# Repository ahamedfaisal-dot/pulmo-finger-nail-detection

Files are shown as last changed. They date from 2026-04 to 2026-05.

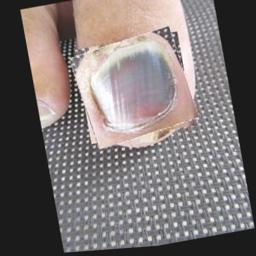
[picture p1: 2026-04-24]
rpi_input1/bf.jpg

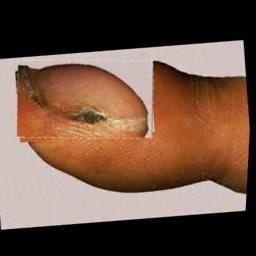
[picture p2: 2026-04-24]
rpi_input1/cl.jpg

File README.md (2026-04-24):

# Finger-Based Lung Health Classification System

> **Edge AI · Raspberry Pi · MobileNetV2 · CAM Explainability · Multi-Sensor Fusion**

A non-invasive, real-time lung health screening system that classifies three clinical conditions directly from a fingertip photograph, fused with live biometric readings (temperature, heart rate, SpO₂) — all running on a Raspberry Pi 4 as a self-contained medical edge device.

---

## Table of Contents

1. [Clinical Background](#-clinical-background)
2. [System Architecture](#-system-architecture)
3. [Project Structure](#-project-structure)
4. [Machine Learning Pipeline (PC / Training Side)](#-machine-learning-pipeline-pc--training-side)
5. [Raspberry Pi Deployment (rpi\_input/)](#-raspberry-pi-deployment-rpi_input)
   - [Hardware Requirements](#hardware-requirements)
   - [Wiring Diagram](#wiring-diagram)
   - [Software Setup on RPi](#software-setup-on-rpi)
   - [Running the System](#running-the-system)
   - [Web Interface &amp; Endpoints](#web-interface--endpoints)
   - [LED Feedback System](#led-feedback-system)
   - [Database &amp; Reports](#database--reports)
6. [Grad-CAM Explainability](#-grad-cam-explainability)
7. [3D Printed Enclosure](#-3d-printed-enclosure)
8. [Troubleshooting](#-troubleshooting)
9. [Class Definitions](#-class-definitions)

---

## Clinical Background

Certain lung and oxygenation disorders manifest visually in the fingertips:

| Condition | Visual Indicator | Root Cause |
| --- | --- | --- |
| **Bluefinger (Cyanosis)** | Bluish/purple discoloration | Severe oxygen deficiency (SpO₂ < 85%) |
| **Clubbing** | Rounded, bulging fingertips | Chronic lung disease (COPD, fibrosis, cancer) |
| **Healthy** | Normal pink coloration | Normal lung function |

This system automates the visual assessment by training a deep CNN on finger images and fusing the result with real-time SpO₂ and temperature data from hardware sensors.

---

## System Architecture

```
┌─────────────────────────────────────────────────────────┐
│                   TRAINING SIDE (PC/GPU)                 │
│                                                          │
│   train/ dataset  ──►  train_export.py                  │
│   (3 classes,         MobileNetV2 fine-tune             │
│    256×256 images)    15 epochs, best_model.pt          │
│                        │                                │
│                        ▼                                │
│                   export_cam.py                         │
│                   (hook last conv layer)                │
│                   Finger19_lung_cam.onnx +              │
│                   cam_weights.npy                       │
└──────────────┬──────────────────────────────────────────┘
               │   Copy .onnx + .npy  via SCP/USB
               ▼
┌─────────────────────────────────────────────────────────┐
│               RASPBERRY PI 4 (Edge Device)               │
│                                                          │
│  ┌─────────────┐   ┌───────────────┐  ┌──────────────┐ │
│  │  RPi Camera │   │  MLX90614     │  │  MAX30102    │ │
│  │  (rpicam)   │   │  IR Temp      │  │  HR + SpO₂  │ │
│  └──────┬──────┘   └───────┬───────┘  └──────┬───────┘ │
│         │                  │  I²C Bus         │         │
│         ▼                  └─────────┬────────┘         │
│    image_bytes              sensor_utils.py             │
│         │                            │                  │
│         └────────────┬───────────────┘                  │
│                      ▼                                   │
│               rpi_input/app.py                          │
│               Flask Web Server (:5000)                  │
│                      │                                   │
│          ┌───────────┼───────────────┐                  │
│          ▼           ▼               ▼                  │
│     ONNX Inference  CAM         SQLite DB               │
│     (3-class pred)  Overlay     diagnostics.db          │
│          │                           │                  │
│          ▼                           ▼                  │
│     LED GPIO Pins               PDF Reports             │
│     (17 / 27 / 22)              via /report/<id>        │
└─────────────────────────────────────────────────────────┘
```

---

## Project Structure

```
Finger_256_lung/
│
├── train/                        # Training dataset (not committed – see .gitignore)
│   ├── Bluefinger/               # Class 0: Oxygen deficiency
│   ├── Clubbing/                 # Class 1: Chronic lung disease
│   └── Healthy/                  # Class 2: Normal
│
├── test/                         # Held-out test images
│
├── train_export.py               # Main training script (MobileNetV2 → ONNX)
├── export_cam.py                 # Exports CAM-capable ONNX + cam_weights.npy
├── inspect_mat.py                # Utility to inspect .mat dataset files
│
├── Finger19_lung.onnx            # Standard ONNX model (no CAM outputs)
├── best_model.pt                 # PyTorch checkpoint (best validation accuracy)
│
├── app.py                        # Standalone Flask demo (PC use, no sensors)
├── requirements.txt              # PC/dev dependencies
│
├── rpi_input/                    # ← DEPLOY THIS FOLDER TO THE RASPBERRY PI
│   ├── app.py                    # Main RPi Flask application
│   ├── sensor_utils.py           # MLX90614 + MAX30102 driver & signal processing
│   ├── Finger19_lung_cam.onnx    # CAM-enabled ONNX model (2 outputs)
│   ├── cam_weights.npy           # Pre-extracted CAM classifier weights
│   ├── requirements_rpi.txt      # RPi Python dependencies
│   │
│   ├── templates/
│   │   ├── index.html            # Home page (live camera feed + upload)
│   │   ├── result.html           # Diagnosis result with CAM overlay
│   │   └── report.html           # Printable/shareable report page
│   │
│   └── hardware_3d_model/
│       └── enclosure.scad        # OpenSCAD enclosure design for the device
│
└── .gitignore
```

---

## Machine Learning Pipeline (PC / Training Side)

### Step 1 — Prepare the Dataset

Organize training images into sub-folders by class:

```
train/
  Bluefinger/   ← finger images showing cyanosis
  Clubbing/     ← finger images showing clubbing
  Healthy/      ← normal healthy finger images
```

Each image should be a clear, well-lit photograph of a fingertip (minimum 100 images per class recommended for good generalization).

### Step 2 — Install PC Dependencies

```bash
pip install torch torchvision onnx onnxruntime flask numpy Pillow opencv-python
```

Or use GPU-accelerated training (requires CUDA):

```bash
pip install torch torchvision --index-url https://download.pytorch.org/whl/cu118
```

### Step 3 — Train the Model

```bash
python train_export.py
```

**What this does:**

- Loads the dataset from `train/` using `ImageFolder`
- Applies data augmentation: random flip, rotation ±15°, color jitter
- Fine-tunes **MobileNetV2** (pretrained on ImageNet) with a 3-class head
- Trains for **15 epochs** with Adam optimizer (lr=1e-3, StepLR scheduler)
- Saves the best checkpoint as `best_model.pt`
- Exports a standard ONNX model: `Finger19_lung.onnx`

**Expected output:**

```
Using device: cuda
Classes: ['Bluefinger', 'Clubbing', 'Healthy']
Epoch 01/15 | Loss=0.9123 | Train=68.3% | Val=71.2%
...
Epoch 15/15 | Loss=0.1204 | Train=97.1% | Val=94.8%
Best val acc: 94.8%
Exported ONNX → Finger19_lung.onnx
```

### Step 4 — Export CAM-Capable Model

```bash
python export_cam.py
```

**What this does:**

- Hooks into MobileNetV2's final convolutional layer to extract feature maps
- Exports a dual-output ONNX: `Finger19_lung_cam.onnx`
  - **Output 0**: class logits `[1, 3]`
  - **Output 1**: feature maps from last conv layer `[1, C, H, W]`
- Saves the classifier weights as `cam_weights.npy` for fast CAM computation at inference

---

## Raspberry Pi Deployment (`rpi_input/`)

### Hardware Requirements

| Component | Model | Interface |
| --- | --- | --- |
| Microcontroller | Raspberry Pi 4 (2 GB+ RAM) | — |
| Camera | Official RPi Camera Module v2 or v3 | CSI ribbon cable |
| IR Temperature Sensor | MLX90614 | I²C (SDA/SCL) |
| Heart Rate + SpO₂ | MAX30102 | I²C (SDA/SCL) |
| Status LEDs | Standard 5 mm LEDs × 3 (Red, Yellow, Green) | GPIO (BCM) |
| Resistors | 220 Ω × 3 | In series with each LED |
| Enclosure | 3D printed (see `hardware_3d_model/enclosure.scad`) | — |

---

### Wiring Diagram

#### I²C Sensors (Both share the same I²C bus)

```
Raspberry Pi 4 GPIO Header
─────────────────────────────────────────────────────
Pin 1  (3.3 V)  ──────────────┬─── MLX90614 VIN
                              └─── MAX30102 VIN

Pin 6  (GND)    ──────────────┬─── MLX90614 GND
                              └─── MAX30102 GND

Pin 3  (SDA1)   ──────────────┬─── MLX90614 SDA
                              └─── MAX30102 SDA

Pin 5  (SCL1)   ──────────────┬─── MLX90614 SCL
                              └─── MAX30102 SCL
─────────────────────────────────────────────────────
```

> **Note:** Add 4.7 kΩ pull-up resistors from SDA and SCL to 3.3 V if your breakout boards don't already include them.

#### LED Indicators (GPIO BCM Numbering)

```
Raspberry Pi GPIO                LED
──────────────────────────────────────────────
GPIO 17 (Pin 11) ── 220 Ω ── [Blue/Red LED]   Bluefinger (Oxygen deficiency)
GPIO 27 (Pin 13) ── 220 Ω ── [Yellow LED]     Clubbing (Chronic lung disease)
GPIO 22 (Pin 15) ── 220 Ω ── [Green LED]      Healthy (Normal)
GND      (Pin 9) ──────────── All LED cathodes
──────────────────────────────────────────────
```

Only the LED corresponding to the predicted class illuminates after each scan. All others go LOW.

---

### Software Setup on RPi

#### 1. Flash OS & Enable Interfaces

Flash **Raspberry Pi OS (64-bit, Bookworm)** and enable required interfaces:

```bash
sudo raspi-config
```

- **Interface Options → Camera** → Enable
- **Interface Options → I2C** → Enable
- Reboot

#### 2. Verify Camera

```bash
rpicam-hello --timeout 3000
```

You should see a brief camera preview. If using a legacy camera with an older OS, ensure `dtoverlay=imx219` is in `/boot/config.txt`.

#### 3. Verify I²C Sensors

```bash
sudo apt install -y i2c-tools
i2cdetect -y 1
```

Expected output (addresses may differ slightly):

```
     0  1  2  3  4  5  6  7  8  9  a  b  c  d  e  f
50: -- -- -- -- -- -- -- 57                          ← MAX30102
5a: 5a -- -- -- -- -- -- --                          ← MLX90614
```

#### 4. Transfer Project Files

Copy the `rpi_input/` folder to the Pi (replace `<PI_IP>` with your Pi's IP address):

```bash
scp -r rpi_input/ pi@<PI_IP>:/home/pi/lung_system/
```

Or use a USB drive and copy manually.

**The critical files that must be present on the RPi:**

```
lung_system/
├── app.py
├── sensor_utils.py
├── Finger19_lung_cam.onnx      ← generated by export_cam.py on PC
├── cam_weights.npy             ← generated by export_cam.py on PC
├── requirements_rpi.txt
└── templates/
    ├── index.html
    ├── result.html
    └── report.html
```

#### 5. Install Python Dependencies

```bash
cd /home/pi/lung_system/
python3 -m venv venv
source venv/bin/activate
pip install --upgrade pip
pip install -r requirements_rpi.txt
```

> **Note on `onnxruntime`:** On Raspberry Pi (ARM64), install the ARM-optimized wheel if the standard pip install fails:
>
> ```bash
> pip install onnxruntime   # Try standard first
> # If it fails, use:
> pip install onnxruntime-aarch64
> ```

---

### Running the System

#### Manual Start

```bash
cd /home/pi/lung_system/
source venv/bin/activate
python app.py
```

The Flask server starts on **`http://0.0.0.0:5000`**. Access it from any device on the same network:

```
http://<PI_IP>:5000
```

#### Auto-Start on Boot (systemd Service)

Create a service file to start automatically:

```bash
sudo nano /etc/systemd/system/lunghealth.service
```

Paste the following (adjust paths as needed):

```ini
[Unit]
Description=Lung Health Classification System
After=network.target

[Service]
User=pi
WorkingDirectory=/home/pi/lung_system
ExecStart=/home/pi/lung_system/venv/bin/python /home/pi/lung_system/app.py
Restart=always
RestartSec=5

[Install]
WantedBy=multi-user.target
```

Enable and start:

```bash
sudo systemctl daemon-reload
sudo systemctl enable lunghealth.service
sudo systemctl start lunghealth.service
sudo systemctl status lunghealth.service
```

---

### Web Interface & Endpoints

| Route | Method | Description |
| --- | --- | --- |
| `/` | GET | Home page — shows live sensor readings, camera feed, and upload form |
| `/video_feed` | GET | MJPEG live camera stream (embedded in the home page) |
| `/get_sensors` | GET | JSON endpoint for live sensor polling (called via AJAX every 2 s) |
| `/capture_predict` | POST | Triggers `rpicam-jpeg` to capture a frame and run inference |
| `/predict` | POST | Accepts an uploaded image file and runs inference |
| `/report/<report_id>` | GET | Shows the full historical diagnostic report by UUID |

#### Example Sensor JSON Response (`/get_sensors`)

```json
{
  "temperature": 36.8,
  "heart_rate": 74,
  "spo2": 98
}
```

#### Example Prediction Flow

1. User places finger on MAX30102 sensor pad
2. Taps **"Capture & Analyse"** on the web UI
3. `rpicam-jpeg` captures a 640×480 JPEG in ~1 s
4. Image is preprocessed (resize → 256×256, ImageNet normalization)
5. ONNX inference runs → logits + feature maps
6. Softmax gives class probabilities
7. CAM overlay is generated from `cam_weights.npy` × feature maps
8. LED on predicted class GPIO pin goes HIGH
9. Result page shows:
   - Predicted class + confidence
   - All class probabilities
   - Original image + CAM heatmap overlay
   - Live sensor readings at time of capture
10. Result is saved to `diagnostics.db` with a unique report UUID

---

### LED Feedback System

The Raspberry Pi uses three GPIO-connected LEDs to provide instant physical feedback without needing to look at the screen:

```python
LED_PINS = [17, 27, 22]  # Index 0 = Bluefinger, 1 = Clubbing, 2 = Healthy
```

After each inference, only the LED at `LED_PINS[pred_idx]` is set HIGH; the rest are set LOW. This makes the result immediately visible even from a distance.

---

### Database & Reports

All diagnostic results are stored in **SQLite** at `diagnostics.db`:

```sql
CREATE TABLE diagnostics (
    id         TEXT PRIMARY KEY,     -- UUID
    timestamp  DATETIME,             -- Auto-set to current time
    temp       REAL,                 -- Body temperature (°C)
    hr         INTEGER,              -- Heart rate (BPM)
    spo2       INTEGER,              -- Blood oxygen (%)
    class_name TEXT,                 -- Predicted class label
    confidence REAL,                 -- Model confidence (%)
    img_b64    TEXT,                 -- Base64 original image
    cam_b64    TEXT                  -- Base64 CAM overlay image
);
```

Each report is accessible at:

```
http://<PI_IP>:5000/report/<uuid>
```

This URL can be shared, bookmarked, or opened via a QR code for printable clinic-style reports.

---

## 🔥 Grad-CAM Explainability

Class Activation Mapping (CAM) highlights **which pixels the model focused on** when making its decision. This is critical for clinical trust — it shows doctors whether the model is looking at the fingertip (correct) or the background (incorrect).

**How it works in this system:**

1. `export_cam.py` hooks into MobileNetV2's last convolutional layer during export
2. The ONNX model now outputs **two tensors**: logits and the feature map
3. `cam_weights.npy` stores the classifier's weight matrix `[3 classes × C channels]`
4. At inference: `CAM = ReLU( Σ w_c · feature_map_c )` for the predicted class
5. The resulting activation map is:
   - Upsampled to 256×256 with bicubic interpolation
   - Gaussian-blurred for smoothness
   - Converted to a JET colormap heatmap
   - Alpha-blended (70% weight) over the original image

The result reveals exactly which part of the finger — tip, nail, or skin — drove the classification decision.

---

## Troubleshooting

| Problem | Cause | Fix |
| --- | --- | --- |
| `rpicam-jpeg: command not found` | Camera tools not installed | `sudo apt install -y rpicam-apps` |
| Camera black screen / no output | Camera not enabled in raspi-config  | Run `sudo raspi-config` → Interface Options → Camera |
| `No module named 'smbus2'` | smbus2 not installed | `pip install smbus2` |
| `No module named 'RPi'` | RPi.GPIO not installed | `pip install RPi.GPIO` |
| I²C sensors not detected at `i2cdetect` | Wrong wiring or I²C not enabled | Check SDA/SCL connections; enable via raspi-config |
| ONNX model fails to load | Wrong path or missing file | Confirm `Finger19_lung_cam.onnx` is in the same folder as `app.py` |
| `onnxruntime` install fails on ARM | Incompatible wheel | Try `pip install onnxruntime-aarch64` or install from source |
| SpO₂ reads "Finger?" | Finger not placed on MAX30102 | Press fingertip firmly on sensor; signal threshold is `red > 5000` |
| SpO₂ reads "Calib..." | Buffer not full yet (< 150 samples) | Wait ~3 seconds after placing finger |
| LED not lighting | GPIO wiring issue | Verify LED polarity (long leg → GPIO, short leg → GND via 220 Ω) |
| Flask not accessible from phone | Wrong host binding | Ensure `app.run(host="0.0.0.0", port=5000)` — do NOT use `127.0.0.1` |

---

## Class Definitions

| Index | Class Name | Display Label | Clinical Meaning |
| ----- | --- | --- | --- |
| 0 | `Bluefinger` | Bluefinger – Oxygen Deficiency  | Peripheral cyanosis caused by low arterial O₂ saturation |
| 1 | `Clubbing` | Clubbing – Chronic Lung Disease | Nail clubbing associated with COPD, pulmonary fibrosis, lung cancer |
| 2 | `Healthy` | Healthy – Normal Lung Function  | Normal fingertip coloration, no clinical indicators |

---

> **⚠️ Disclaimer:** This system is an educational and research prototype. It is **not a certified medical device** and should not be used as the sole basis for any clinical diagnosis. Always consult a qualified healthcare professional.

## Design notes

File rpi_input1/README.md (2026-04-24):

# Raspberry Pi 4 - Finger Lung Health System

This sub-folder contains the code and configuration for running the system on a Raspberry Pi 4 Model B (4GB) with I2C health sensors.

## 1. Hardware Connections (I2C)

Both sensors are connected to the Raspberry Pi's I2C pins:
- **SDA**: Pin 3 (GPIO 2)
- **SCL**: Pin 5 (GPIO 3)
- **VCC**: 3.3V (Pin 1 or 17)
- **GND**: Ground (Pin 6, 9, etc.)

| Sensor | SDA | SCL | VCC | GND |
| :--- | :--- | :--- | :--- | :--- |
| **MLX90614** (Temp) | Connect | Connect | 3.3V | Ground |
| **MAX30102** (HR) | Connect | Connect | 3.3V | Ground |

## 2. RPi Software Setup

1. **Enable I2C**:
   - Run `sudo raspi-config`
   - Go to `Interfacing Options` -> `I2C` -> `Yes`
   - Reboot your Pi.

2. **Verify Sensors**:
   - Run `sudo i2cdetect -y 1`
   - You should see `0x5A` (MLX90614) and `0x57` (MAX30102) in the grid.

## 3. Installation

```bash
# Create a virtual environment
python3 -m venv venv
source venv/bin/activate

# Install dependencies
pip install -r requirements_rpi.txt
```

## 4. Run the System

```bash
python app.py
```
After running, access the dashboard via your browser using the Pi's IP address:
`http://<YOUR_PI_IP>:5000`

## Features
- **Real-time Monitoring**: The web UI polls the I2C sensors every 3 seconds for live Temperature, Heart Rate, and SpO2.
- **On-Device Classification**: Runs the retrained 96.8% accuracy ONNX model directly on the RPi CPU.

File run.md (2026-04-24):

# Finger Lung Classification System - Documentation

This project provides a web-based interface to classify lung conditions (Bluefinger, Clubbing, or Healthy) based on finger images. Since the original ONNX model provided was not performing correctly, a new model was trained on the provided dataset.

## 1. Model Architecture
- **Base Model**: **MobileNetV2** (Pre-trained on ImageNet).
- **Modification**: The final classification layer was replaced with a 3-unit linear layer to match your dataset.
- **Input Size**: 256x256 pixels (RGB).
- **Inference Engine**: ONNX Runtime (CPU/GPU compatible).

## 2. Training Details
- **Hardware**: Trained using the local **NVIDIA RTX 3050 GPU**.
- **Dataset**: ~1,700 images across 3 classes.
- **Preprocessing**: 
  - Resized to 256x256.
  - ImageNet normalization (Mean: `[0.485, 0.456, 0.406]`, Std: `[0.229, 0.224, 0.225]`).
  - Augmentations: Random horizontal flip, rotation, and color jitter.
- **Performance**: Achieved **96.8% Validation Accuracy** after 15 epochs.
- **Script**: The training logic is available in `train_export.py`.

## 3. Setup & Installation
The system is already set up in this directory with a virtual environment.

### Activation
```powershell
.\venv\Scripts\activate
```

### Dependencies
Installed via `requirements.txt`:
- `flask`: Web framework.
- `onnxruntime`: Efficient inference engine.
- `numpy & Pillow`: Image processing.

## 4. How to Run the Application
1. **Start the Server**:
   ```powershell
   python app.py
   ```
2. **Access the Web Interface**:
   Open your browser and go to: **[http://127.0.0.1:5000](http://127.0.0.1:5000)**
3. **Classify**:
   - Upload an image from the `train/`, `test/`, or `Result/` folders.
   - Click **Classify**.
   - Review the predicted class and the confidence breakdown for all categories.

## 5. File Structure
- `app.py`: The Flask backend.
- `Finger19_lung.onnx`: The retrained, high-accuracy model.
- `templates/index.html`: The user interface.
- `train_export.py`: The script used to train the model.
- `venv/`: The main virtual environment for running the app.
- `venv_gpu/`: (Optional) Temporary environment used for GPU training.

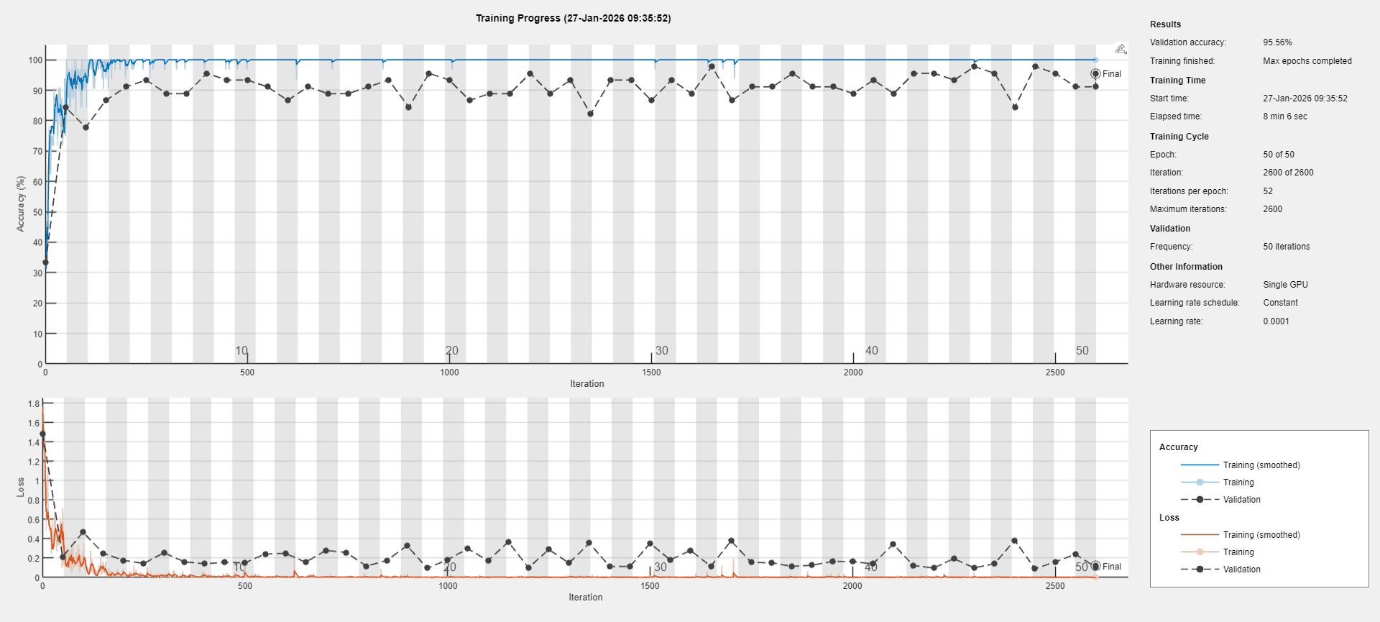
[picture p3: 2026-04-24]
TN.png

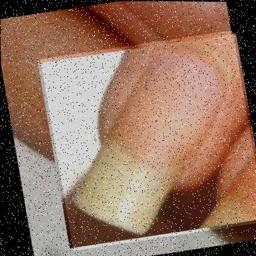
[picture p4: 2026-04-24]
rpi_input1/nr.jpg

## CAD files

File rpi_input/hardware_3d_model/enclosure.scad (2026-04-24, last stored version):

// Life Trace Edge Hub - 3D Printable Enclosure
// Compatible with OpenSCAD (https://openscad.org/)
// 
// This script generates a parameterized 3D model for your project.
// Render it in OpenSCAD and export as STL for your 3D printer.

/* [Dimensions] */
box_width = 120;
box_length = 90;
box_height = 50;
wall_thickness = 2;

/* [Finger Cradle] */
finger_radius = 12;
finger_length = 50;

/* [Raspberry Pi Mount] */
pi_width = 85;
pi_length = 56;
mount_height = 5;

module base_box() {
    difference() {
        // Outer Shell
        cube([box_width, box_length, box_height], center=true);
        // Inner Cavity
        translate([0, 0, wall_thickness])
            cube([box_width - wall_thickness*2, box_length - wall_thickness*2, box_height], center=true);
    }
}

module finger_cradle() {
    // A rounded cut-out on the top surface where the user places their finger
    translate([0, box_length/2 - finger_length/2 - 10, box_height/2])
        rotate([90, 0, 0])
            cylinder(r=finger_radius, h=finger_length, center=true, $fn=50);
}

module sensor_cutouts() {
    // Hole for Raspberry Pi Camera (pointing at the finger)
    // Assuming camera is mounted above or looking directly at the finger
    translate([0, box_length/2 - 25, box_height/2 - finger_radius])
        cylinder(r=5, h=10, center=true, $fn=30);
        
    // Hole for MAX30102 Heart Rate Sensor (bottom of the finger cradle)
    translate([-10, box_length/2 - 30, box_height/2 - finger_radius])
        cylinder(r=4, h=10, center=true, $fn=30);
        
    // Hole for MLX90614 Temperature Sensor
    translate([10, box_length/2 - 30, box_height/2 - finger_radius])
        cylinder(r=4, h=10, center=true, $fn=30);
}

module pi_mounts() {
    // Simple mounting standoffs for Raspberry Pi 4
    mount_x = pi_width/2 - 3.5;
    mount_y = pi_length/2 - 3.5;
    
    translate([0, -10, -box_height/2 + wall_thickness/2 + mount_height/2]) {
        for (x = [-mount_x, mount_x]) {
            for (y = [-mount_y, mount_y]) {
                translate([x, y, 0])
                    difference() {
                        cylinder(r=3, h=mount_height, center=true, $fn=20);
                        cylinder(r=1.2, h=mount_height+1, center=true, $fn=20); // Screw hole
                    }
            }
        }
    }
}

// Assemble the final case
difference() {
    union() {
        base_box();
        pi_mounts();
    }
    // Subtract the finger cradle and sensor holes from the top
    finger_cradle();
    sensor_cutouts();
    
    // Add port cutouts for Raspberry Pi (Power/HDMI)
    translate([box_width/2, -10, -box_height/2 + 10])
        cube([10, 40, 15], center=true);
}

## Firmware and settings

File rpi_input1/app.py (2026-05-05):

import os
import io
import base64
import numpy as np
import cv2
import subprocess
import sqlite3
import uuid
from PIL import Image
import onnxruntime as ort
from flask import Flask, render_template, request, jsonify, Response
# from sensor_utils import get_sensor_data  # No longer using local sensors for temp/HR

try:
    import RPi.GPIO as GPIO
    GPIO.setmode(GPIO.BCM)
    GPIO.setwarnings(False)
    # Define LED pins for classes: Bluefinger (17), Clubbing (27), Healthy (22)
    LED_PINS = [17, 27, 22] 
    for pin in LED_PINS:
        GPIO.setup(pin, GPIO.OUT)
        GPIO.output(pin, GPIO.LOW)
    GPIO_AVAILABLE = True
except ImportError:
    GPIO_AVAILABLE = False

app = Flask(__name__)

# Global storage for sensor data from ESP8266
latest_sensor_data = {
    "temperature": "N/A",
    "heart_rate": "N/A",
    "spo2": "N/A"
}


# Initialize SQLite Database
DB_FILE = os.path.join(os.path.dirname(__file__), "diagnostics.db")
def init_db():
    conn = sqlite3.connect(DB_FILE)
    c = conn.cursor()
    c.execute('''CREATE TABLE IF NOT EXISTS diagnostics
                 (id TEXT PRIMARY KEY, timestamp DATETIME DEFAULT CURRENT_TIMESTAMP,
                  temp REAL, hr INTEGER, spo2 INTEGER, class_name TEXT, 
                  confidence REAL, img_b64 TEXT, cam_b64 TEXT)''')
    conn.commit()
    conn.close()

init_db()


MODEL_PATH = os.path.join(os.path.dirname(__file__), "Finger19_lung_cam.onnx")
WEIGHTS_PATH = os.path.join(os.path.dirname(__file__), "cam_weights.npy")
try:
    session = ort.InferenceSession(MODEL_PATH)
    CAM_WEIGHTS = np.load(WEIGHTS_PATH)
except:
    session = None
    CAM_WEIGHTS = None

CLASS_NAMES = [
    "Bluefinger- Oxygen deficiency",
    "Clubbing- Chronic lung disease",
    "Healthy- Normal lung function",
]

# ImageNet normalization
NORM_MEAN = np.array([0.485, 0.456, 0.406]).reshape(3, 1, 1)
NORM_STD  = np.array([0.229, 0.224, 0.225]).reshape(3, 1, 1)

def preprocess(image_bytes):
    img = Image.open(io.BytesIO(image_bytes)).convert("RGB")
    img = img.resize((256, 256))
    arr = np.array(img, dtype=np.float32) / 255.0
    arr = arr.transpose(2, 0, 1)
    arr = (arr - NORM_MEAN) / NORM_STD
    return np.expand_dims(arr, axis=0).astype(np.float32)

@app.route("/")
def index():
    # Use the latest data received from ESP8266
    return render_template("index.html", result=None, sensors=latest_sensor_data)

@app.route("/get_sensors")
def get_sensors():
    """Endpoint for live sensor updates via AJAX."""
    return jsonify(latest_sensor_data)

@app.route("/update_sensors", methods=["POST"])
def update_sensors():
    """Endpoint for ESP8266 to POST new sensor data."""
    global latest_sensor_data
    try:
        data = request.get_json()
        if not data:
            return jsonify({"status": "error", "message": "No data"}), 400
        
        # Update our global store
        latest_sensor_data["temperature"] = data.get("temperature", "N/A")
        latest_sensor_data["heart_rate"] = data.get("heart_rate", "N/A")
        latest_sensor_data["spo2"] = data.get("spo2", "N/A")
        
        return jsonify({"status": "success"}), 200
    except Exception as e:
        return jsonify({"status": "error", "message": str(e)}), 500


def _process_image_bytes(image_bytes):
    global session, CAM_WEIGHTS
    if session is None or CAM_WEIGHTS is None:
        try: 
            session = ort.InferenceSession(MODEL_PATH)
            CAM_WEIGHTS = np.load(WEIGHTS_PATH)
        except: return None

    input_tensor = preprocess(image_bytes)

    # Run inference
    outputs = session.run(None, {session.get_inputs()[0].name: input_tensor})
    logits = outputs[0][0]
    features = outputs[1][0] if len(outputs) > 1 else None
    exp_l = np.exp(logits - np.max(logits))
    probs = exp_l / exp_l.sum()

    pred_idx = int(np.argmax(probs))
    
    # Update LEDs based on the predicted class index
    if GPIO_AVAILABLE:
        for idx, pin in enumerate(LED_PINS):
            if idx == pred_idx:
                GPIO.output(pin, GPIO.HIGH)
            else:
                GPIO.output(pin, GPIO.LOW)
    
    img_b64 = base64.b64encode(image_bytes).decode("utf-8")

    cam_b64 = None
    if CAM_WEIGHTS is not None and features is not None:
        try:
            w = CAM_WEIGHTS[pred_idx]
            cam = np.tensordot(w, features, axes=([0], [0]))
            cam = np.maximum(cam, 0) # ReLU

            cam_resized = cv2.resize(cam, (256, 256), interpolation=cv2.INTER_CUBIC)
            c_min, c_max = cam_resized.min(), cam_resized.max()
            if c_max - c_min > 0:
                cam_resized = (cam_resized - c_min) / (c_max - c_min)

            cam_resized = cv2.GaussianBlur(cam_resized, (15, 15), 0)

            cam_uint8 = np.uint8(255 * cam_resized)
            heatmap = cv2.applyColorMap(cam_uint8, cv2.COLORMAP_JET)
            heatmap_float = heatmap.astype(np.float32)

            orig_img_bgr = cv2.cvtColor(np.array(Image.open(io.BytesIO(image_bytes)).convert("RGB").resize((256, 256))), cv2.COLOR_RGB2BGR).astype(np.float32)

            alpha = cam_resized[..., np.newaxis] * 0.7 
            overlay = (orig_img_bgr * (1 - alpha) + heatmap_float * alpha)
            overlay = np.clip(overlay, 0, 255).astype(np.uint8)

            _, buffer = cv2.imencode('.jpg', overlay)
            cam_b64 = base64.b64encode(buffer).decode("utf-8")
        except Exception as e:
            print("CAM generation failed:", e)

    result = {
        "class_name": CLASS_NAMES[pred_idx],
        "confidence": round(float(probs[pred_idx]) * 100, 2),
        "image_data": img_b64,
        "cam_data": cam_b64,
        "all_probs": [
            {"class_name": name, "confidence": round(float(probs[i]) * 100, 2)}
            for i, name in enumerate(CLASS_NAMES)
        ]
    }
    return result

def capture_image_rpicam():
    try:
        cmd = [
            "rpicam-jpeg",
            "--width", "640",
            "--height", "480",
            "--nopreview",
            "--timeout", "1000",
            "--output", "-"
        ]
        result = subprocess.run(cmd, capture_output=True, timeout=10)
        if result.returncode == 0 and len(result.stdout) > 0:
            return result.stdout
        else:
            print("rpicam-jpeg error:", result.stderr.decode(errors="replace"))
            return None
    except Exception as e:
        print("Exception capturing with rpicam-jpeg:", e)
        return None

@app.route("/capture_predict", methods=["POST"])
def capture_predict():
    image_bytes = capture_image_rpicam()
    sensors = latest_sensor_data

    if not image_bytes:
        return render_template("index.html", result=None, sensors=sensors, error="Failed to capture image from camera.")
    
    result = _process_image_bytes(image_bytes)
    if not result:
        return render_template("index.html", result=None, sensors=sensors, error="Model not ready.")
        
    # Save to database
    report_id = str(uuid.uuid4())
    temp = sensors.get('temperature', 0)
    hr = sensors.get('heart_rate', 0)
    spo2 = sensors.get('spo2', 0)
    
    # Handle 'Calib...' or 'Finger?' non-numeric edge cases
    try: temp = float(temp)
    except: temp = 0.0
    try: hr = int(hr)
    except: hr = 0
    try: spo2 = int(spo2)
    except: spo2 = 0

    conn = sqlite3.connect(DB_FILE)
    c = conn.cursor()
    c.execute("INSERT INTO diagnostics (id, temp, hr, spo2, class_name, confidence, img_b64, cam_b64) VALUES (?, ?, ?, ?, ?, ?, ?, ?)",
              (report_id, temp, hr, spo2, result['class_name'], result['confidence'], result['image_data'], result['cam_data']))
    conn.commit()
    conn.close()
        
    return render_template("result.html", result=result, sensors=sensors, report_id=report_id)

@app.route("/predict", methods=["POST"])
def predict():
    file = request.files.get("image")
    sensors = latest_sensor_data
    if not file: 
        return render_template("index.html", result=None, sensors=sensors)


    image_bytes = file.read()
    result = _process_image_bytes(image_bytes)
    if not result:
        return render_template("index.html", result=None, sensors=sensors, error="Model not ready.")
        
    # Save to database
    report_id = str(uuid.uuid4())
    temp = sensors.get('temperature', 0)
    hr = sensors.get('heart_rate', 0)
    spo2 = sensors.get('spo2', 0)
    
    try: temp = float(temp)
    except: temp = 0.0
    try: hr = int(hr)
    except: hr = 0
    try: spo2 = int(spo2)
    except: spo2 = 0

    conn = sqlite3.connect(DB_FILE)
    c = conn.cursor()
    c.execute("INSERT INTO diagnostics (id, temp, hr, spo2, class_name, confidence, img_b64, cam_b64) VALUES (?, ?, ?, ?, ?, ?, ?, ?)",
              (report_id, temp, hr, spo2, result['class_name'], result['confidence'], result['image_data'], result['cam_data']))
    conn.commit()
    conn.close()
        
    return render_template("result.html", result=result, sensors=sensors, report_id=report_id)

@app.route("/report/<report_id>")
def view_report(report_id):
    conn = sqlite3.connect(DB_FILE)
    c = conn.cursor()
    c.execute("SELECT timestamp, temp, hr, spo2, class_name, confidence, img_b64, cam_b64 FROM diagnostics WHERE id = ?", (report_id,))
    row = c.fetchone()
    conn.close()
    
    if not row:
        return "Report not found", 404
        
    timestamp, temp, hr, spo2, class_name, confidence, img_b64, cam_b64 = row
    
    result = {
        "class_name": class_name,
        "confidence": confidence,
        "image_data": img_b64,
        "cam_data": cam_b64,
    }
    sensors = {
        "temperature": temp,
        "heart_rate": hr,
        "spo2": spo2
    }
    
    return render_template("report.html", result=result, sensors=sensors, timestamp=timestamp)

camera_process = None

def generate_mjpeg():
    global camera_process
    if camera_process is not None:
        try:
            camera_process.terminate()
            camera_process.wait(timeout=2)
        except:
            pass
            
    cmd = [
        "rpicam-vid",
        "--width", "640",
        "--height", "480",
        "--framerate", "15",
        "--codec", "mjpeg",
        "--timeout", "0",
        "--nopreview",
        "--output", "-"
    ]
    camera_process = subprocess.Popen(cmd, stdout=subprocess.PIPE, stderr=subprocess.DEVNULL, bufsize=10**8)
    
    bytes_buffer = b''
    try:
        while True:
            chunk = camera_process.stdout.read(4096)
            if not chunk:
                break
            bytes_buffer += chunk
            a = bytes_buffer.find(b'\xff\xd8')
            b = bytes_buffer.find(b'\xff\xd9')
            if a != -1 and b != -1:
                jpg = bytes_buffer[a:b+2]
                bytes_buffer = bytes_buffer[b+2:]
                yield (b'--frame\r\n'
                       b'Content-Type: image/jpeg\r\n\r\n' + jpg + b'\r\n')
    except GeneratorExit:
        if camera_process:
            camera_process.terminate()

@app.route("/video_feed")
def video_feed():
    return Response(generate_mjpeg(), mimetype='multipart/x-mixed-replace; boundary=frame')


if __name__ == "__main__":
    # RPi recommended to run on 0.0.0.0 to be accessible via IP
    app.run(host="0.0.0.0", port=5000, debug=True)

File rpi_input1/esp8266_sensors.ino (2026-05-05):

#include <ESP8266WiFi.h>
#include <ESP8266HTTPClient.h>
#include <WiFiClient.h>
#include <Wire.h>
#include "MAX30105.h"
#include "heartRate.h"
#include <Adafruit_MLX90614.h>

// ================= WIFI =================
const char* ssid     = "Don't smuggle_2G";
const char* password = "azam1502";

// ================= SERVER =================
const char* serverIP = "192.168.0.200";   // Raspberry Pi IP
const int serverPort = 5000;

// ================= SENSOR OBJECTS =================
MAX30105 particleSensor;
Adafruit_MLX90614 mlx = Adafruit_MLX90614();

// ================= HEART RATE =================
const byte RATE_SIZE = 4;
byte rates[RATE_SIZE];
byte rateSpot = 0;
long lastBeat = 0;

float beatsPerMinute;
int beatAvg = 0;

// ================= SETUP =================
void setup() {
  Serial.begin(115200);
  delay(1000);

  Serial.println("\nESP8266 Sensor Node Starting...");

  // I2C Start
  Wire.begin(D2, D1);
  Wire.setClock(100000);

  // MAX30102 Init
  Serial.println("Initializing MAX30102...");
  if (!particleSensor.begin(Wire, I2C_SPEED_STANDARD)) {
    Serial.println("MAX30102 not found!");
    while (1);
  }

  particleSensor.setup();
  particleSensor.setPulseAmplitudeRed(0x1F);
  particleSensor.setPulseAmplitudeGreen(0);

  Serial.println("MAX30102 Ready");

  // MLX90614 Init
  Serial.println("Initializing MLX90614...");
  if (!mlx.begin()) {
    Serial.println("MLX90614 not found!");
    while (1);
  }

  Serial.println("MLX90614 Ready");

  // WiFi Connect
  connectWiFi();
}

// ================= LOOP =================
void loop() {

  // Reconnect WiFi if disconnected
  if (WiFi.status() != WL_CONNECTED) {
    connectWiFi();
  }

  long irValue = particleSensor.getIR();

  // Beat Detection
  if (checkForBeat(irValue)) {
    long delta = millis() - lastBeat;
    lastBeat = millis();

    beatsPerMinute = 60 / (delta / 1000.0);

    if (beatsPerMinute < 255 && beatsPerMinute > 20) {
      rates[rateSpot++] = (byte)beatsPerMinute;
      rateSpot %= RATE_SIZE;

      beatAvg = 0;
      for (byte x = 0; x < RATE_SIZE; x++) {
        beatAvg += rates[x];
      }
      beatAvg /= RATE_SIZE;
    }
  }

  // Report every 2 sec
  static unsigned long lastReport = 0;
  if (millis() - lastReport > 2000) {
    lastReport = millis();

    float objTemp = mlx.readObjectTempC();

    int hrToSend = 0;
    int spo2ToSend = 0;

    if (irValue > 50000) {   // Finger detected
      hrToSend = beatAvg;
      spo2ToSend = 98;       // placeholder
    }

    Serial.print("IR: ");
    Serial.print(irValue);
    Serial.print(" | Temp: ");
    Serial.print(objTemp);
    Serial.print(" C | HR: ");
    Serial.print(hrToSend);
    Serial.print(" | SpO2: ");
    Serial.println(spo2ToSend);

    sendToPi(objTemp, hrToSend, spo2ToSend);
  }
}

// ================= WIFI FUNCTION =================
void connectWiFi() {
  Serial.print("Connecting to WiFi");

  WiFi.begin(ssid, password);

  int attempts = 0;
  while (WiFi.status() != WL_CONNECTED && attempts < 30) {
    delay(500);
    Serial.print(".");
    attempts++;
  }

  if (WiFi.status() == WL_CONNECTED) {
    Serial.println("\nWiFi connected!");
    Serial.print("IP Address: ");
    Serial.println(WiFi.localIP());
  } else {
    Serial.println("\nWiFi Failed!");
  }
}

// ================= SEND DATA =================
void sendToPi(float t, int h, int s) {
  if (WiFi.status() == WL_CONNECTED) {
    WiFiClient client;
    HTTPClient http;

    String url = "http://" + String(serverIP) + ":" + String(serverPort) + "/update_sensors";

    Serial.println("Sending to: " + url);

    http.begin(client, url);
    http.addHeader("Content-Type", "application/json");

    String payload = "{\"temperature\":" + String(t, 1) +
                     ",\"heart_rate\":" + String(h) +
                     ",\"spo2\":" + String(s) + "}";

    int httpCode = http.POST(payload);

    if (httpCode > 0) {
      Serial.printf("HTTP Response code: %d\n", httpCode);
      String response = http.getString();
      Serial.println(response);
    } else {
      Serial.printf("HTTP POST failed: %s\n", http.errorToString(httpCode).c_str());
    }

    http.end();
  }
}
